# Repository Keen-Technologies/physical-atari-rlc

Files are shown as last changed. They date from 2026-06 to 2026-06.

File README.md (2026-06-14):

# **[Physical Atari: A Robust and Accessible Platform for Real-time Reinforcement Learning on Robots](https://keenagi.com/research/physical-atari/)**  
Khurram Javed, Joseph Modayil, Gloria Kennickell, Richard S. Sutton, John Carmack

## Overview

- **Devbox** (Raspberry Pi): runs `PhysicalALE`, displays the game and AprilTags on a Waveshare screen.
- **Agent machine** (Linux): camera observes the Devbox screen, Robotroller servos press the joystick, and `agent_code` runs training/evaluation.

## Setup

### 1. Build Robotroller

- Follow the [Robotroller assembly guide](https://keenagi.com/research/physical-atari/robotroller.html).
- Configure servo IDs and baud rate before first use (see [Hardware setup](#hardware-setup) below).

### 2. Set up the Devbox

The microSD card cannot be inserted or removed once the chassis is built. Order:

1. Flash **Raspberry Pi OS Full** (64-bit, Debian 13 "trixie") and insert the SD card — see [devbox_code/README.md](devbox_code/README.md#flash-raspberry-pi-os).
2. Assemble the Devbox — follow the [Devbox assembly guide](https://keenagi.com/research/physical-atari/devbox.html).
3. Clone this repository, install dependencies, and build `PhysicalALE` (see [devbox_code/README.md](devbox_code/README.md)).
4. Place Atari 2600 ROMs in a directory (e.g. `devbox_code/games/`).
5. Launch a game: `PhysicalALE ./games/ pong`

### 3. Set up the agent machine

On the Linux machine with the camera and Robotroller:

1. Build and install the I/O library (see [input_output_cpp_library/README.md](input_output_cpp_library/README.md)).
2. Install Python dependencies:
   ```bash
   cd agent_code
   pip install -r requirements.txt
   ```
3. Create a local Robotroller config (see [agent_code/README.md#robotroller-config](agent_code/README.md#robotroller-config)):
   ```bash
   cp physical_atari_configs/robotroller.default.json physical_atari_configs/physical_atari_sample_config.json
   ```
   Edit `physical_atari_sample_config.json` for your camera device and serial port.

### 4. Run a random agent

With the Devbox running a game:

```bash
# On Devbox
PhysicalALE ./games/ pong

# On agent machine (from agent_code/)
python learn_policy.py --config experiment_configs/agent_random_real.json --run 0
```

For sim-only testing (no hardware), see [agent_code/README.md](agent_code/README.md).

## Hardware setup

Before using the physical environment, configure each Dynamixel XC330 servo. Factory defaults are ID **1** and baud rate **57600**. The Robotroller expects three servos on the same bus at baud rate **1,000,000**:

| ID | Role |
|----|---|
| 50 | Fire button |
| 51 | Left/right D-pad |
| 52 | Up/down D-pad |

Configure one servo at a time (only one device on the bus during programming):

1. Connect a USB serial adapter to the **agent machine** (not the Devbox).
2. Install dependencies: from the repository root, `pip install -r setup_scripts/requirements.txt`
3. Find the serial port: `ls /dev/serial/by-id/`
4. Connect **one** servo and power it.
5. Assign the target ID with [`setup_scripts/change_id.py`](setup_scripts/change_id.py) (use `--baud_rate 57600` for factory-default servos).
6. Set baud rate to 1,000,000 with [`setup_scripts/change_baud_rate.py`](setup_scripts/change_baud_rate.py).
7. Disconnect that servo, connect the next, and repeat.

Set `SERIAL` to your device path. Example for the fire-button servo:

```bash
# Assign ID 50 (communicate at factory baud 57600)
python setup_scripts/change_id.py --path "$SERIAL" --current_id 1 --new_id 50 --baud_rate 57600

# Switch servo to 1 Mbps (required by the Robotroller library)
python setup_scripts/change_baud_rate.py --path "$SERIAL" --id 50 --current_baud_rate 57600 --new_baud_rate 1000000
```

Repeat for the left/right servo (ID 51) and up/down servo (ID 52).

Once all three servos are configured, connect them together on the same bus. Set `robot.serial_port` in your Robotroller config — see [agent_code/README.md#robotroller-config](agent_code/README.md#robotroller-config).

## Repository layout

| Directory | Purpose |
|---|---|
| [`agent_code/`](agent_code/) | RL training, evaluation, and finetuning ([README](agent_code/README.md)) |
| [`devbox_code/`](devbox_code/) | Devbox emulator (`PhysicalALE`) ([README](devbox_code/README.md)) |
| [`input_output_cpp_library/`](input_output_cpp_library/) | Camera, AprilTag, and servo I/O (`robotroller` module) ([README](input_output_cpp_library/README.md)) |
| [`setup_scripts/`](setup_scripts/) | Dynamixel servo ID and baud rate configuration |
| [`3d_model_files/`](3d_model_files/) | Printable STLs, Blender/Fusion archives, and exchange formats for Devbox and Robotroller |

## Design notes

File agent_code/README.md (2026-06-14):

# Agent scripts

Run commands from the `agent_code/` directory. For hardware assembly and servo setup, see the [root README](../README.md).

Install dependencies with `pip install -r requirements.txt`. **ale-py 0.12+** is required (older versions return action IDs differently and break `sim_env`).

Training runs save checkpoints to local directories (see `checkpoint_dir` in experiment configs).

For visualization and camera tools, see [scripts/README.md](scripts/README.md).

## Robotroller config

Physical runs need a machine-specific robotroller config (camera and servo settings). Config files live under `agent_code/physical_atari_configs/`:

| File | Purpose |
|---|---|
| `physical_atari_configs/robotroller.default.json` | Committed template with default values |
| `physical_atari_configs/physical_atari_sample_config.json` | Local config used at runtime (gitignored) |

Copy the template to create your local config, then edit camera and robot settings for your machine:

```bash
cp physical_atari_configs/robotroller.default.json physical_atari_configs/physical_atari_sample_config.json
```

Edit `physical_atari_sample_config.json` (e.g. `camera.device`, `robot.serial_port`, servo positions).

Physical experiment configs (e.g. `experiment_configs/agent_action_input_real.json`) specify the config path:

```json
"robotroller_config_path": ["./physical_atari_configs/physical_atari_sample_config.json"]
```

The resolved path is stored in checkpoint `results.json` so `evaluate_policy.py` and `finetune_policy.py` can reuse it when run with `--env real`. Override with `--robotroller-config` if needed.

If you have an existing home-directory config, copy it once:

```bash
cp ~/robotroller.conf physical_atari_configs/physical_atari_sample_config.json
```

## agent_random

Test the sim or physical stack with random actions (replaces the old `test_python.py` hardware test). The agent picks a new uniform random action every frame; no training or weight checkpoints are saved (`store_weights: false` in the random experiment configs).

For physical runs, set up your robotroller config first (see **Robotroller config** above).

Sim test:

```bash
python learn_policy.py --config experiment_configs/agent_random_sim.json --run 0
```

Physical test (launch the game on the devbox first, e.g. `PhysicalALE ./games/ pong`):

```bash
python learn_policy.py --config experiment_configs/agent_random_real.json --run 0
```

## learn_policy.py

Trains or benchmarks an agent based on a configuration file.

### Usage

```bash
python learn_policy.py --config experiment_configs/agent_action_input_sim.json --run 0
```

Checkpoints are written to `{checkpoint_dir}/{run_name}/` with `results.json`, `weights.pkl`, and observation state files.

### Arguments

*   `--config`: Path to the JSON configuration file containing hyperparameters.
*   `--run`: Integer index to select a specific configuration from the cross-product of parameters defined in the JSON file.
*   `--gpu`: (Optional) GPU device ID to use.

### Physical environment

Launch the game on the devbox before training:

```bash
# On devbox
PhysicalALE ./games/ pong

# On agent machine
python learn_policy.py --config experiment_configs/agent_action_input_real.json --run 0
```

The default real config (`experiment_configs/agent_action_input_real.json`) sets `device` to `cuda`. Change it to `cpu` in that JSON if you do not have a CUDA GPU.

---

## evaluate_policy.py

Loads a trained model from a checkpoint directory and evaluates its performance.

### Usage

```bash
python evaluate_policy.py --checkpoint-dir ./checkpoints/pong__agents.agent_action_input__0__20260612-120000
```

### Arguments

*   `--checkpoint-dir`: Path to a training run directory (contains `results.json` and `weights.pkl`).
*   `--eval_steps`: Number of steps to run the evaluation (default: 20000).
*   `--device`: Device to run evaluation on (e.g., `cpu`, `cuda`, `mps`).
*   `--env`: Environment type (`sim` or `real`; default: `sim`).
*   `--robotroller-config`: Path to robotroller config when `--env real` (overrides checkpoint).
*   `--comment`: Optional comment logged with evaluation results.

Eval results are saved to `{checkpoint-dir}/eval_results.json`.

---

## finetune_policy.py

Loads a trained model, evaluates it (pre-finetune), fine-tunes it, and evaluates again (post-finetune).

### Usage

```bash
python finetune_policy.py --checkpoint-dir ./checkpoints/pong__...__0__<timestamp> --learning_steps 100000
```

### Arguments

*   `--checkpoint-dir`: Path to source checkpoint run directory.
*   `--eval_before_steps`: Evaluation steps before fine-tuning (default: 18000).
*   `--learning_steps`: Number of fine-tuning steps (required).
*   `--eval_after_steps`: Evaluation steps after fine-tuning (default: 18000).
*   `--device`: Device to run on (e.g., `cpu`, `cuda`, `mps`).
*   `--env`: Environment type (`sim` or `real`; default: `sim`).
*   `--robotroller-config`: Path to robotroller config when `--env real` (overrides checkpoint).
*   `--comment`: Optional comment logged with finetune results.

Fine-tuned weights are saved to a new run directory under `checkpoint_dir`. Summary metrics are written to `{checkpoint-dir}/finetune_results.json`.

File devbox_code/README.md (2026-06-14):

# Devbox Setup

Order of operations:

1. Flash the OS and insert the SD card (the microSD slot is not accessible after assembly).
2. Assemble the Devbox chassis.
3. Clone this repository and build `PhysicalALE`.

Runs on a Raspberry Pi devbox: builds and runs the Stella-based Atari emulator (`PhysicalALE`) with AprilTag overlays and GPIO input.

## Flash Raspberry Pi OS

Use a fresh install of **Raspberry Pi OS Full** (Debian 13 "trixie", 64-bit). Do not upgrade from Bookworm in place — flash a clean image.

1. Download and install [Raspberry Pi Imager](https://www.raspberrypi.com/software/) on your computer.
2. Insert the Devbox microSD card (or connect the Pi's storage via USB).
3. In Imager:
   - **Choose Device** → **Raspberry Pi 5**
   - **Choose OS** → **Raspberry Pi OS (other)** → **Raspberry Pi OS Full (64-bit)**
   - **Choose Storage** → your microSD card
4. Open **OS Customisation** (gear icon) and set hostname, user, password, locale, and Wi‑Fi if needed. Enable SSH if you plan to set up headlessly.
5. Click **Write**, then insert the card into the Pi.

Insert the SD card **before** assembling the chassis — the slot is not accessible afterward.

## Assemble the Devbox

Follow the [Devbox assembly guide](https://keenagi.com/research/physical-atari/devbox.html).

## Install software

On the assembled Devbox, clone this repository and work from the `devbox_code` directory.

Update the system:

```sh
sudo apt update && sudo apt full-upgrade -y
```

Install build dependencies:

```sh
sudo apt install -y libsdl2-dev libgpiod-dev cmake build-essential pkg-config
```

Build and install `PhysicalALE`:

```sh
cd devbox_code
mkdir -p build && cd build
cmake ..
make -j"$(nproc)"
sudo make install   # installs PhysicalALE to /usr/local/bin
```

## ROM files

We do not ship ROM files in this repository. You must place supported Atari 2600 ROMs in a directory (e.g. `./games/`) before running `PhysicalALE`.

The easiest way to get them is via [ale_py](https://github.com/Farama-Foundation/Arcade-Learning-Environment), which bundles supported ROMs in the pip package (ale-py 0.12+):

```sh
pip install ale-py
mkdir -p games
python3 -c "from ale_py import roms; import shutil; from pathlib import Path; d=Path('games'); [shutil.copy(p, d/f'{n}.bin') for n in roms.get_all_rom_ids() if (p:=roms.get_rom_path(n))]"
```

On Raspberry Pi OS, if `pip install` fails because system Python is externally managed, use a virtual environment or pass `--break-system-packages` to `pip install ale-py`.

## Run

```sh
cd devbox_code
PhysicalALE ./games/ pong
PhysicalALE ./games/ pong my_experiment   # optional override for results filename
```

Usage: `PhysicalALE <RomDirectory> <game_name> [results_filename]`

On shutdown, results are saved locally to `{game_name}_{timestamp}.json` (UTC). Pass an optional third argument to override the filename (saved as `{results_filename}.json`).

## Keyboard controls

Requires a USB keyboard connected to the Pi.

- `T`: Toggle corner AprilTag visibility
- `F`: Toggle FPS counter
- `Q`: Quit

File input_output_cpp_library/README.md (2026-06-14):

# input_output_cpp_library

I/O layer for the physical Atari setup: camera capture, AprilTag detection, and Robotroller servo actions. The primary deliverable is the `robotroller` Python module, which exposes `PhysicalAtariEnv` (used by RL training), `Camera`, and `Robotroller`.

**Prerequisites:** Build the Robotroller hardware, assign servo IDs 50, 51, and 52, and set baud rate to 1,000,000 — see [Hardware setup](../README.md#hardware-setup) in the root README.

For hardware config, tests, and training scripts, see [agent_code/README.md](../agent_code/README.md).

## 1. Install dependencies

### Ubuntu

```bash
sudo apt update
sudo apt install -y build-essential cmake git libopencv-dev python3-dev python3-pybind11 libapriltag-dev
```

### Dynamixel SDK

```bash
git clone https://github.com/ROBOTIS-GIT/DynamixelSDK.git
cd DynamixelSDK/c++
mkdir build && cd build
cmake ..
make
sudo make install
cd ../../..
```

### Miniconda (optional)

For Python environment management:

```bash
wget https://repo.anaconda.com/miniconda/Miniconda3-latest-Linux-x86_64.sh
bash Miniconda3-latest-Linux-x86_64.sh
source ~/.bashrc
```

## 2. Build and install

Build from the same Python environment you will use for training — `cmake` installs the module into the active `python` interpreter's site-packages.

```bash
cd input_output_cpp_library
mkdir -p build && cd build
cmake ..
make
sudo make install
```

Verify the module is available:

```bash
python3 -c "import robotroller; print(robotroller.__doc__)"
```

## License

Copyright 2026 Keen Technologies, Inc.

Licensed under the Apache License, Version 2.0. See the [repository LICENSE](../LICENSE) for the full text.

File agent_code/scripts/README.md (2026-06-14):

# Scripts

Run these from the `agent_code/` directory.

## visualize_stream.py

Records agent observations from the sim or real environment to an MP4.

```bash
# Sim
python scripts/visualize_stream.py \
  --env sim \
  --game pong \
  --output pong_sim.mp4

# Real (game must be running on the devbox; create physical_atari_sample_config.json first — see agent README Robotroller config)
python scripts/visualize_stream.py \
  --env real \
  --config physical_atari_configs/physical_atari_sample_config.json \
  --game pong \
  --output pong_real.mp4
```

Common flags: `--frames` (default 1000), `--output-fps` (default 30), `--random-policy`, `--no-text`.

## camera_focus_sweep.py

Records a video while sweeping camera focus from 200 to 600 (step 10, 2s per value). Writes `focus_sweep.mp4`.

```bash
python scripts/camera_focus_sweep.py \
  --config-path physical_atari_configs/robotroller.default.json
```

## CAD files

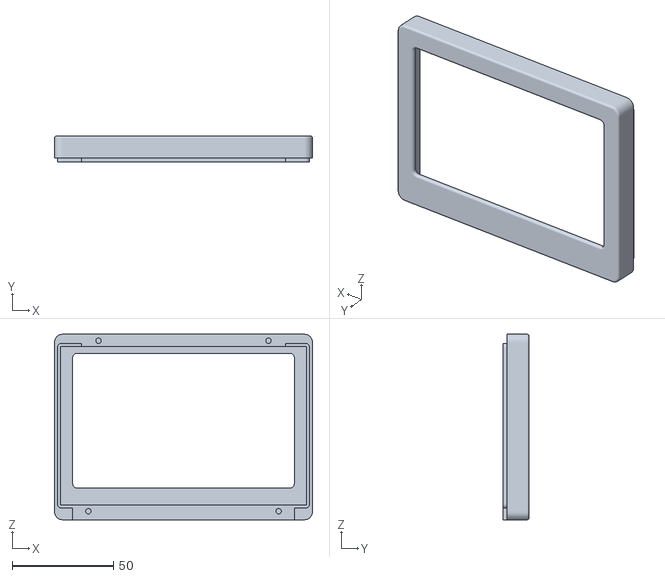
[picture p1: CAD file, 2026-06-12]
3d_model_files/3d_printer_files/devbox/Front.stl
127.5 x 13.0 x 91.7

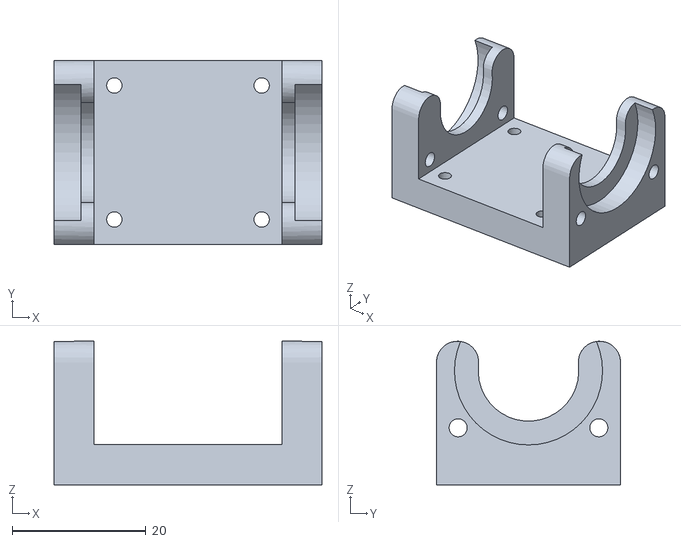
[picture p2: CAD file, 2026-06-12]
3d_model_files/3d_printer_files/robotroller/shoulder.stl
40.0 x 27.5 x 21.4

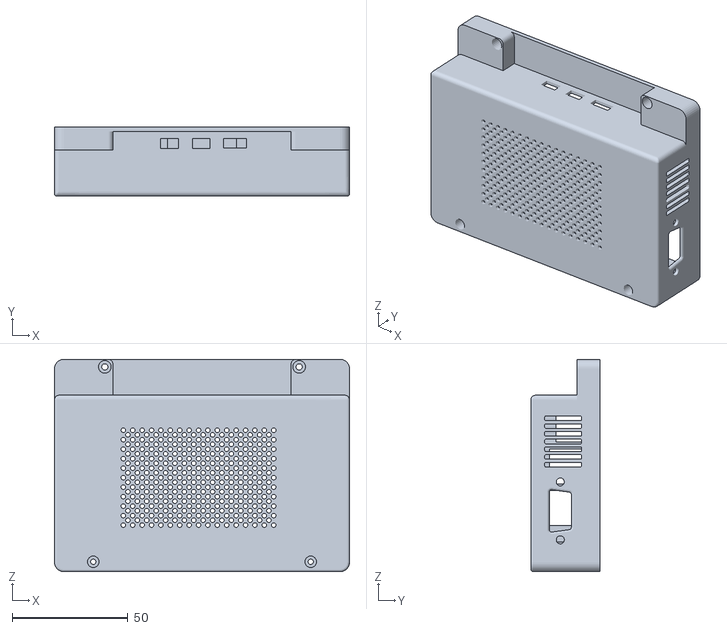
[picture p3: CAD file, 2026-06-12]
3d_model_files/3d_printer_files/devbox/Back.stl
127.5 x 30.0 x 91.7

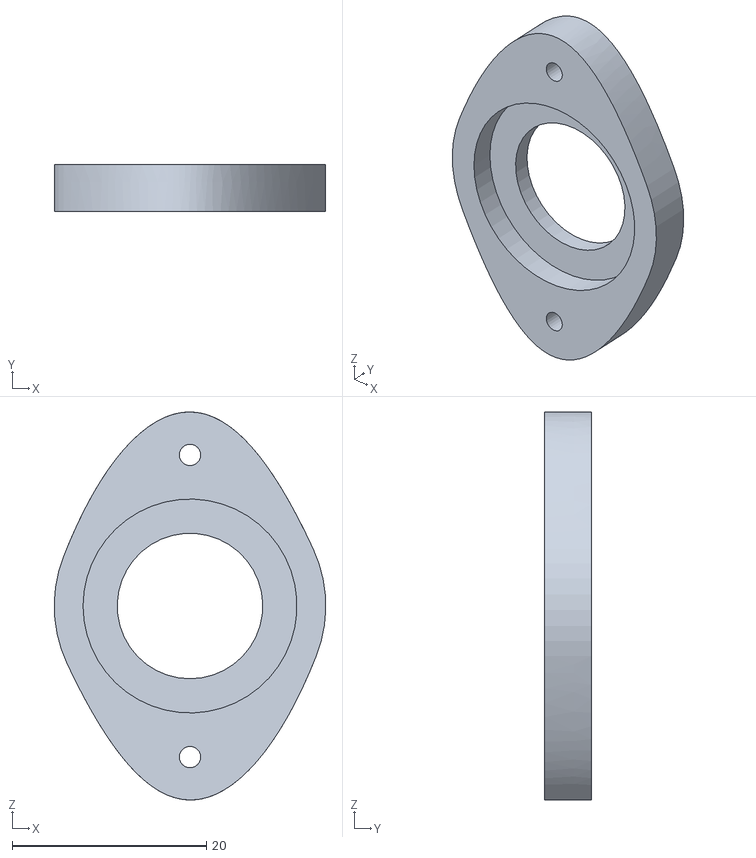
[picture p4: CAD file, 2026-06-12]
3d_model_files/3d_printer_files/robotroller/elbow_cover.stl
28.0 x 4.80 x 40.0

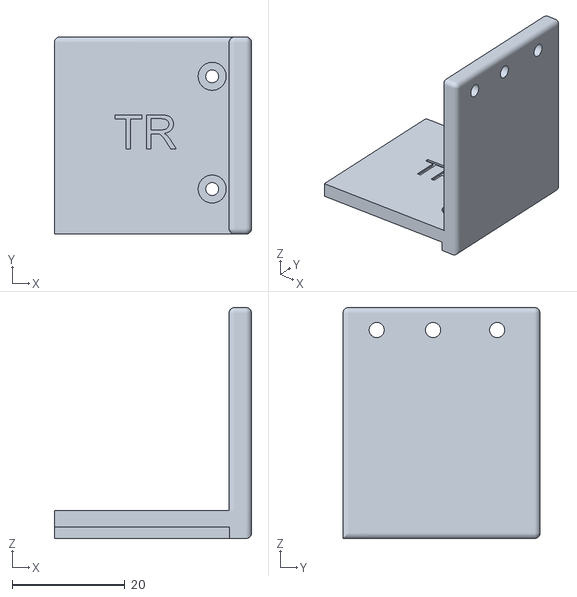
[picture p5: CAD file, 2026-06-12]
3d_model_files/3d_printer_files/robotroller/tr_corner.stl
35.0 x 35.0 x 41.0

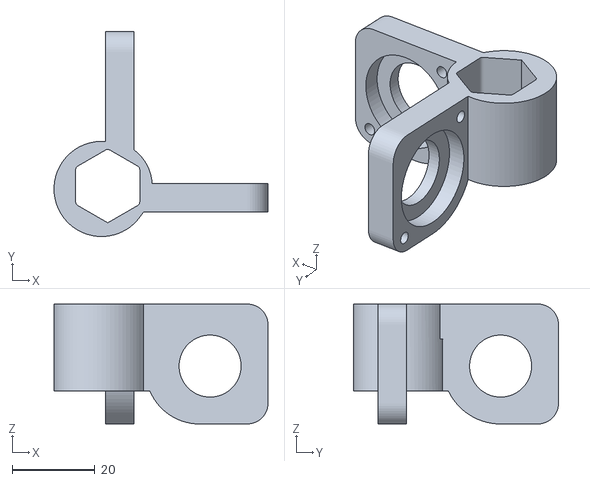
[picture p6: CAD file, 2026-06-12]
3d_model_files/3d_printer_files/robotroller/joystick_attachment.stl
51.7 x 49.6 x 29.0

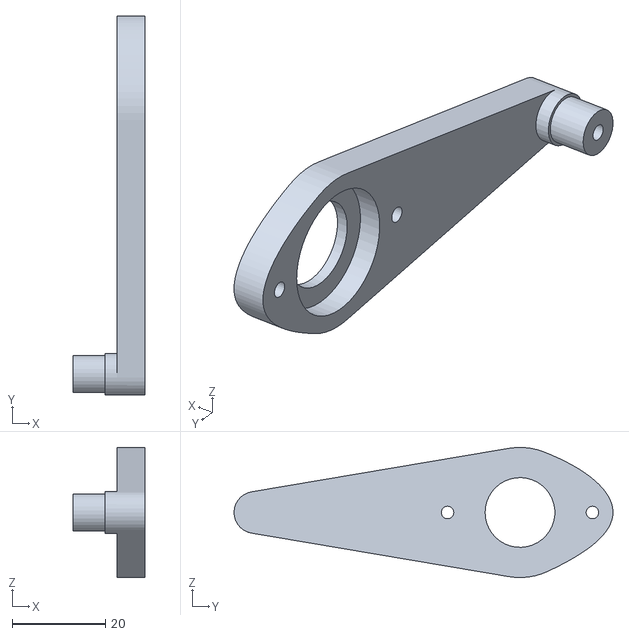
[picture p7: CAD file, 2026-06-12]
3d_model_files/3d_printer_files/robotroller/elbow_to_finger.stl
15.4 x 81.5 x 28.0

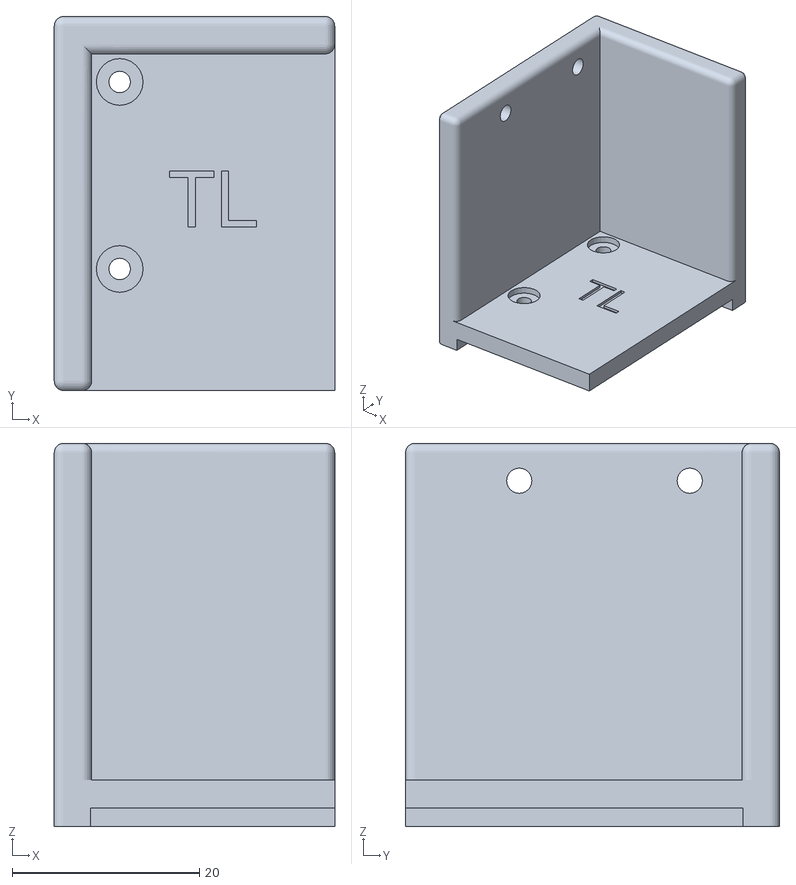
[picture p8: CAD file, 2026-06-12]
3d_model_files/3d_printer_files/robotroller/tl_corner.stl
30.0 x 40.0 x 41.0

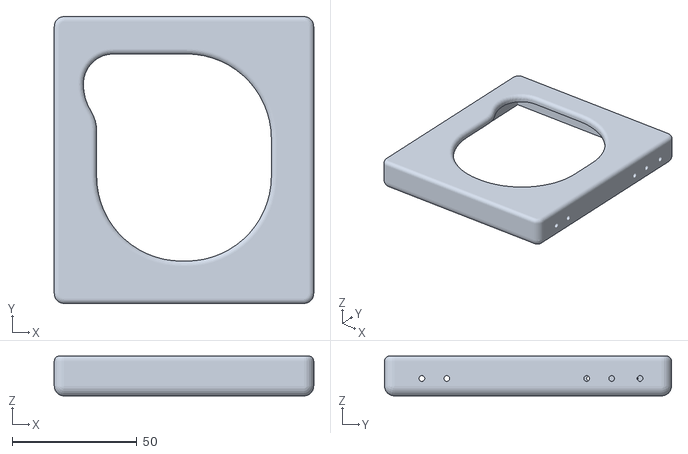
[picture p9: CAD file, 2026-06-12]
3d_model_files/3d_printer_files/robotroller/cx40_cover.stl
104.0 x 115.0 x 16.0

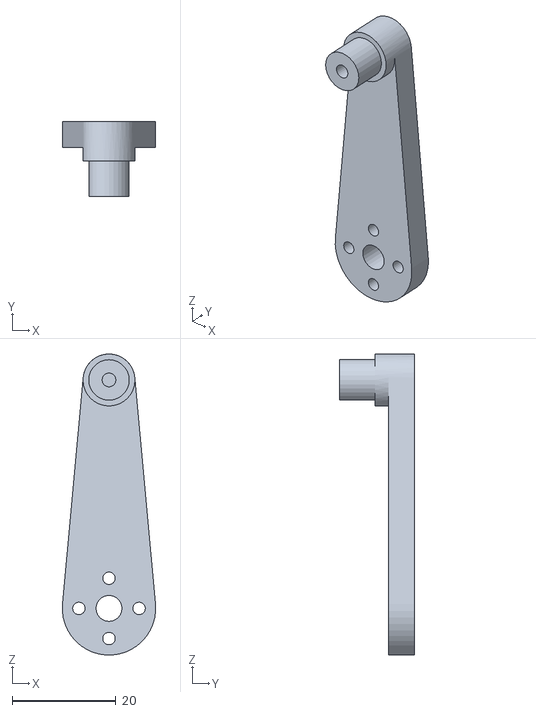
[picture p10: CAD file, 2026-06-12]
3d_model_files/3d_printer_files/robotroller/motor_attachment.stl
18.0 x 14.4 x 58.0

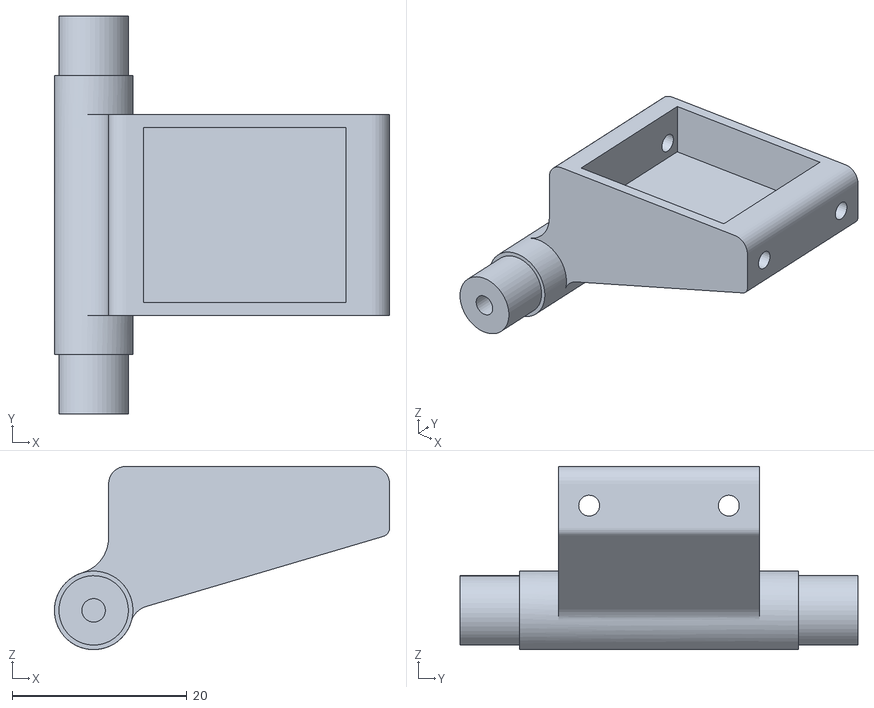
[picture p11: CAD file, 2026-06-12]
3d_model_files/3d_printer_files/robotroller/shoulder_joint.stl
38.4 x 45.6 x 21.0

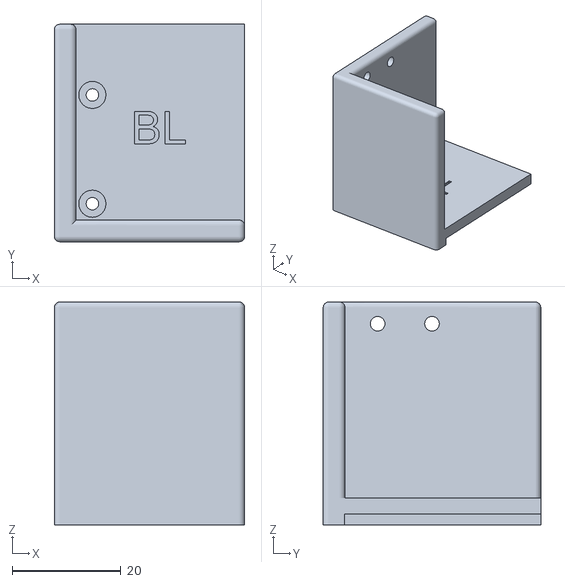
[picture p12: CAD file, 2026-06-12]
3d_model_files/3d_printer_files/robotroller/bl_corner.stl
35.0 x 40.0 x 41.0

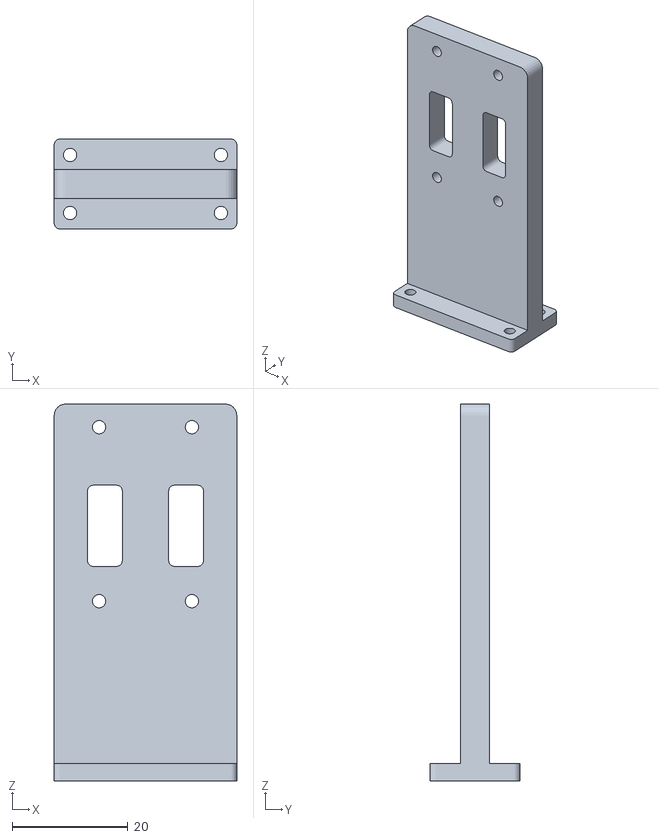
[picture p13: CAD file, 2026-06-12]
3d_model_files/3d_printer_files/robotroller/fire_finger_holder.stl
31.5 x 15.5 x 65.0

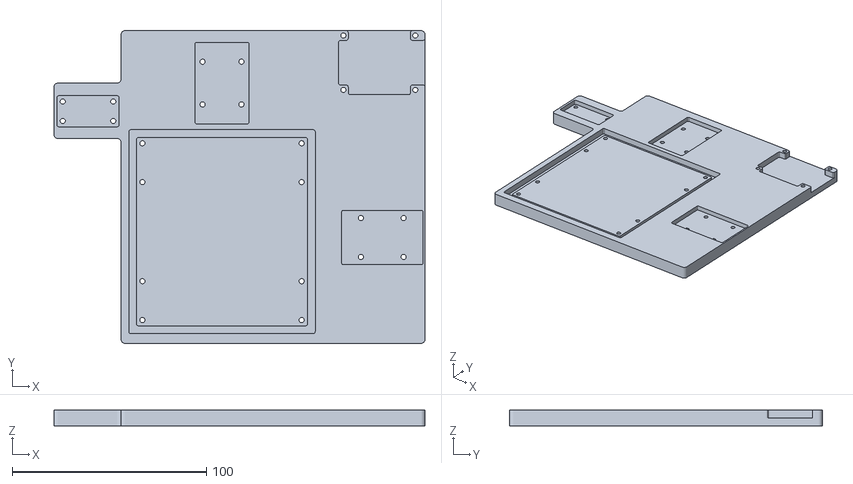
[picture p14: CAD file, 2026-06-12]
3d_model_files/3d_printer_files/robotroller/base_plate.stl
191.0 x 161.0 x 8.00

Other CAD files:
3d_model_files/3d_printer_files/robotroller/shoulder_socket_cover.stl
3d_model_files/3d_printer_files/robotroller/br_corner.stl
3d_model_files/3d_printer_files/robotroller/joystick_attachment_cover.stl
3d_model_files/3d_printer_files/robotroller/fire_finger.stl
3d_model_files/3d_printer_files/robotroller/washer.stl

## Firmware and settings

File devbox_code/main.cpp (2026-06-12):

// Copyright 2026 Keen Technologies, Inc.
//
// Licensed under the Apache License, Version 2.0 (the "License");
// you may not use this file except in compliance with the License.
// You may obtain a copy of the License at
//
//     http://www.apache.org/licenses/LICENSE-2.0
//
// Unless required by applicable law or agreed to in writing, software
// distributed under the License is distributed on an "AS IS" BASIS,
// WITHOUT WARRANTIES OR CONDITIONS OF ANY KIND, either express or implied.
// See the License for the specific language governing permissions and
// limitations under the License.

#include "imgui/imgui.h"
#include "imgui/imgui_impl_sdl2.h"
#include "imgui/imgui_impl_sdlrenderer2.h"
#include "imgui/imgui_theme.h"
#include <chrono>
#include <fstream>

#include <iostream>
#include <vector>
#include <csignal>
#include <cerrno>
#include <cstring>
#include <unordered_map>

#include <gpiod.h>
#include <SDL2/SDL.h>
#include <mutex>
#include "src/atari/ale_interface.hpp"
#include "include/json.hpp"


// Screen Settings
int screen_width = 1280;
int screen_height = 720;

// SDL Core Components
SDL_Window* window;
SDL_Renderer* renderer;
SDL_Texture* game_screen;

// Frame Timing
double fps_estimate = 60;

// ALE Environment and Configuration
ale::ALEInterface* env;
ale::Action current_action = ale::PLAYER_A_NOOP;

// Game State and Rendering
std::vector<unsigned char> input_image;

// Synchronization
std::mutex m;

// Episodic tracking
std::vector<int> episodic_scores;
std::vector<int> episode_lengths;
int current_episode_score = 0;
std::string experiment_name;
std::string game_name_global;
std::chrono::system_clock::time_point start_timestamp;
bool shutdown_requested = false;

static gpiod_line_request* request_input_lines(const char* chip_path,
                                               const unsigned int* offsets,
                                               size_t num_lines,
                                               const char* consumer)
{
    gpiod_chip* chip = gpiod_chip_open(chip_path);
    if (!chip)
        return nullptr;

    gpiod_line_settings* settings = gpiod_line_settings_new();
    if (!settings)
    {
        gpiod_chip_close(chip);
        return nullptr;
    }

    gpiod_line_settings_set_direction(settings, GPIOD_LINE_DIRECTION_INPUT);
    gpiod_line_settings_set_bias(settings, GPIOD_LINE_BIAS_PULL_UP);

    gpiod_line_config* line_cfg = gpiod_line_config_new();
    if (!line_cfg)
    {
        gpiod_line_settings_free(settings);
        gpiod_chip_close(chip);
        return nullptr;
    }

    for (size_t i = 0; i < num_lines; ++i)
    {
        if (gpiod_line_config_add_line_settings(line_cfg, &offsets[i], 1, settings) < 0)
        {
            gpiod_line_config_free(line_cfg);
            gpiod_line_settings_free(settings);
            gpiod_chip_close(chip);
            return nullptr;
        }
    }

    gpiod_request_config* req_cfg = nullptr;
    if (consumer)
    {
        req_cfg = gpiod_request_config_new();
        if (!req_cfg)
        {
            gpiod_line_config_free(line_cfg);
            gpiod_line_settings_free(settings);
            gpiod_chip_close(chip);
            return nullptr;
        }
        gpiod_request_config_set_consumer(req_cfg, consumer);
    }

    gpiod_line_request* request = gpiod_chip_request_lines(chip, req_cfg, line_cfg);

    gpiod_request_config_free(req_cfg);
    gpiod_line_config_free(line_cfg);
    gpiod_line_settings_free(settings);
    gpiod_chip_close(chip);

    return request;
}

static int gpio_pressed(gpiod_line_request* request, unsigned int offset)
{
    enum gpiod_line_value value = gpiod_line_request_get_value(request, offset);
    return value == GPIOD_LINE_VALUE_ACTIVE ? 0 : 1;
}

// Signal handler for graceful shutdown
void signal_handler(int signum)
{
    std::cout << "\n[PhysicalALE] Received signal " << signum << ", shutting down gracefully..." << std::endl;
    m.lock();
    shutdown_requested = true;
    m.unlock();
}

// Function to get ISO 8601 timestamp string
std::string get_iso_timestamp(const std::chrono::system_clock::time_point& tp)
{
    auto time_t_tp = std::chrono::system_clock::to_time_t(tp);
    std::tm tm = *std::gmtime(&time_t_tp);
    char buffer[100];
    std::strftime(buffer, sizeof(buffer), "%Y-%m-%dT%H:%M:%SZ", &tm);
    return std::string(buffer);
}

std::string get_filename_timestamp(const std::chrono::system_clock::time_point& tp)
{
    auto time_t_tp = std::chrono::system_clock::to_time_t(tp);
    std::tm tm = *std::gmtime(&time_t_tp);
    char buffer[32];
    std::strftime(buffer, sizeof(buffer), "%Y%m%d_%H%M%S", &tm);
    return std::string(buffer);
}

// Function to save results to JSON file
void save_results_to_json()
{
    try
    {
        std::cout << "[PhysicalALE] Saving results to JSON file..." << std::endl;
        
        // Create end timestamp
        auto end_timestamp = std::chrono::system_clock::now();
        
        // Build JSON document
        nlohmann::json j;
        j["experiment_name"] = experiment_name;
        j["game"] = game_name_global;
        j["episodic_scores"] = episodic_scores;
        j["episode_lengths"] = episode_lengths;
        j["start_timestamp"] = get_iso_timestamp(start_timestamp);
        j["end_timestamp"] = get_iso_timestamp(end_timestamp);
        
        std::string filename = experiment_name.empty()
            ? game_name_global + "_" + get_filename_timestamp(end_timestamp) + ".json"
            : experiment_name + ".json";
        std::ofstream output_file(filename);
        if (!output_file.is_open())
        {
            std::cerr << "[PhysicalALE] Error: Could not open output file " << filename << std::endl;
            return;
        }
        
        output_file << j.dump(4);  // Pretty print with 4-space indent
        output_file.close();
        
        std::cout << "[PhysicalALE] Results saved to " << filename << std::endl;
        std::cout << "[PhysicalALE] Total episodes: " << episodic_scores.size() << std::endl;
    }
    catch (const std::exception& e)
    {
        std::cerr << "[PhysicalALE] Error saving results to JSON: " << e.what() << std::endl;
    }
}

// Function to generate AprilTag
void GenerateAprilTag(unsigned char* aprilTag, const std::vector<int>& indices)
{
    for (int i = 0; i < 10 * 10 * 4; i++)
    {
        aprilTag[i] = 0;
    }
    for (int i = 0; i < 10; i++)
    {
        for (int j = 0; j < 10; j++)
        {
            if (i == 0 || j == 0 || i == 9 || j == 9)
            {
                aprilTag[i * 10 * 4 + j * 4 + 0] = 255;
                aprilTag[i * 10 * 4 + j * 4 + 1] = 255;
                aprilTag[i * 10 * 4 + j * 4 + 2] = 255;
                aprilTag[i * 10 * 4 + j * 4 + 3] = 255;
            }
        }
    }
    for (auto& ind : indices)
    {
        aprilTag[(ind - 1) * 4 + 0] = 255;
        aprilTag[(ind - 1) * 4 + 1] = 255;
        aprilTag[(ind - 1) * 4 + 2] = 255;
        aprilTag[(ind - 1) * 4 + 3] = 255;
    }
}


int main(int argc, char** argv)
{
    // Record start timestamp
    start_timestamp = std::chrono::system_clock::now();
    
    float frac = 0.625f;

    // Get RomDirectory from command line arguments
    if (argc < 2)
    {
        std::cerr << "Error: RomDirectory required as first command line argument" << std::endl;
        std::cerr << "Usage: " << argv[0] << " <RomDirectory> <game_name> [results_filename]" << std::endl;
        return 1;
    }
    std::string directory = argv[1];

    std::unordered_map<std::string, bool> to_render_flags_map;
    to_render_flags_map["corner_tags"] = true;

    // Get game name and experiment name from command line arguments
    if (argc < 3)
    {
        std::cerr << "Error: Game name required as command line argument" << std::endl;
        std::cerr << "Usage: " << argv[0] << " <RomDirectory> <game_name> [results_filename]" << std::endl;
        return 1;
    }
    std::string game_name = argv[2];
    game_name_global = game_name;
    
    // Get experiment name (optional)
    if (argc >= 4)
    {
        experiment_name = argv[3];
    }
    else
    {
        experiment_name = "";
    }
    
    std::cout << "Game: " << game_name << ", Experiment: " << experiment_name << std::endl;

    // Register signal handler for graceful shutdown
    signal(SIGTERM, signal_handler);
    signal(SIGINT, signal_handler);

    env = new ale::ALEInterface();
    env->setFloat("repeat_action_probability", 0.0);
    env->setInt("frame_skip", 1);
    env->setBool("truncate_on_loss_of_life", false);
    // Ensure directory has trailing slash for proper path joining
    std::string rom_path = directory;
    if (!rom_path.empty() && rom_path.back() != '/') {
        rom_path += "/";
    }
    rom_path += game_name + ".bin";
    env->loadROM(rom_path);

    env->reset_game();
    std::cout << "Env reset complete\n";
    env->act(ale::PLAYER_A_NOOP);
    SDL_Init(SDL_INIT_VIDEO);
    SDL_DisplayMode DM;
    SDL_GetCurrentDisplayMode(0, &DM);

    auto window_flags = static_cast<SDL_WindowFlags>(
        SDL_WINDOW_FULLSCREEN);
    window = SDL_CreateWindow("Atari 2600", SDL_WINDOWPOS_CENTERED,
                              SDL_WINDOWPOS_CENTERED, screen_width, screen_height, window_flags);

    renderer = SDL_CreateRenderer(
        window, -1, SDL_RENDERER_PRESENTVSYNC | SDL_RENDERER_ACCELERATED);
    if (renderer == nullptr)
    {
        SDL_Log("Error creating SDL_Renderer!");
        return 0;
    }

    IMGUI_CHECKVERSION();
    ImGui::CreateContext();
    ImGuiIO& io = ImGui::GetIO();
    (void)io;
    io.ConfigFlags |=
        ImGuiConfigFlags_NavEnableKeyboard; // Enable Keyboard Controls
    io.ConfigFlags |=
        ImGuiConfigFlags_NavEnableGamepad; // Enable Gamepad Controls

    ImGui_ImplSDL2_InitForSDLRenderer(window, renderer);
    ImGui_ImplSDLRenderer2_Init(renderer);

    ImGuiTheme::ApplyTheme(ImGuiTheme::ImGuiTheme_GrayVariations);

    bool done = false;
    int pitch2 = 0;
    void* pixels2;

    std::vector<std::vector<int>> indices = {};
    std::vector<int> tag0 = {23, 24, 26, 28, 34, 35, 36, 38, 44, 45, 53, 55, 64, 66, 67, 76};
    std::vector<int> tag1 = {23, 24, 26, 27, 34, 36, 37, 38, 43, 44, 45, 46, 54, 55, 63, 65, 66, 68, 75, 78};
    std::vector<int> tag2 = {23, 24, 26, 27, 28, 34, 37, 43, 55, 58, 66, 75, 76, 77};
    std::vector<int> tag3 = {23, 24, 25, 28, 36, 37, 38, 43, 46, 47, 48, 53, 55, 58, 63, 64, 67, 74, 75};
    std::vector<int> tag4 = {23, 24, 25, 27, 33, 34, 35, 36, 43, 45, 46, 47, 48, 55, 57, 63, 73, 77};
    std::vector<int> tag5 = {23, 24, 25, 26, 33, 34, 38, 43, 44, 46, 47, 53, 55, 57, 58, 65, 66, 67, 73, 75, 76};
    std::vector<int> tag6 = {28, 34, 36, 37, 43, 45, 48, 54, 55, 56, 58, 67, 76, 78};
    std::vector<int> tag7 = {26, 36, 37, 44, 46, 53, 55, 56, 57, 66, 67, 68, 74, 76};
    std::vector<int> tag8 = {25, 33, 35, 37, 38, 46, 47, 48, 54, 55, 56, 57, 58, 63, 64, 65, 67, 73, 75, 76, 78};
    std::vector<int> tag9 = {25, 28, 33, 36, 38, 43, 45, 47, 48, 54, 64, 68, 73, 74, 77};
    std::vector<int> tag10 = {25, 26, 28, 35, 36, 37, 38, 43, 44, 45, 47, 54, 58, 63, 65, 66, 67, 76, 77};
    std::vector<int> tag11 = {25, 26, 27, 28, 33, 34, 35, 36, 37, 38, 43, 46, 48, 53, 57, 63, 64, 67, 68, 74, 76, 78};
    std::vector<int> tag12 = {24, 33, 34, 35, 37, 45, 48, 54, 57, 58, 65, 67, 74, 75, 77};
    std::vector<int> tag13 = {24, 28, 33, 34, 36, 43, 45, 46, 48, 57, 58, 63, 68, 74, 75, 76, 77, 78};
    std::vector<int> tag14 = {24, 27, 28, 33, 35, 38, 43, 44, 46, 53, 56, 65, 66, 67, 68, 73, 75, 78};
    std::vector<int> tag15 = {24, 26, 33, 36, 44, 45, 54, 56, 63, 66, 67, 73, 75, 76, 77};
    std::vector<int> tag16 = {24, 26, 27, 34, 35, 38, 44, 45, 46, 47, 48, 53, 54, 56, 58, 64, 66, 73, 74, 75};
    std::vector<int> tag17 = {24, 25, 27, 36, 37, 43, 45, 46, 47, 53, 54, 56, 57, 63, 64, 68, 75, 76};
    std::vector<int> tag18 = {24, 25, 27, 33, 34, 35, 36, 37, 44, 47, 53, 56, 57, 58, 65, 73, 74, 78};
    std::vector<int> tag19 = {24,25, 26, 27, 28, 33, 37, 38, 46, 48, 54, 55, 63, 64, 65, 67, 68, 73, 75, 77};
    indices = {
        tag0, tag1, tag2, tag3, tag4, tag5, tag6, tag7, tag8, tag9, tag10, tag11, tag12, tag13, tag14, tag15, tag16,
        tag17, tag18, tag19
    };


    std::vector<SDL_Texture*> aprilTagTextures;
    game_screen = SDL_CreateTexture(renderer, SDL_PIXELFORMAT_RGB24, SDL_TEXTUREACCESS_STREAMING,
                                    static_cast<int>(env->getWidth()),
                                    static_cast<int>(env->getHeight()));
    for (int i = 0; i < 36; i++)
    {
        aprilTagTextures.push_back(SDL_CreateTexture(renderer, SDL_PIXELFORMAT_BGR888, SDL_TEXTUREACCESS_STREAMING,
                                                     10,
                                                     10));
    }

    std::vector<unsigned char> aprilTag(10 * 10 * 4, 0);
    for (int i = 0; i < indices.size(); i++)
    {
        GenerateAprilTag(aprilTag.data(), indices[i]);
        if (SDL_LockTexture(aprilTagTextures[i], nullptr, &pixels2, &pitch2) < 0)
        {
            std::cerr << "Failed to lock texture: " << SDL_GetError() << std::endl;
        };
        std::memcpy(pixels2, aprilTag.data(), pitch2 * 10);
        SDL_UnlockTexture(aprilTagTextures[i]);
    }


    auto old_time = std::chrono::system_clock::now();

    int step_counter = 0;
    int last_nonzero_reward_tag = 10;  // Starts at tag 10 (init condition)
    int change_indicator_tag = 15;     // Cycles through 15, 16, 17
    int current_reward = 0;            // Store reward from each step
    bool show_fps = false;


    std::cout << gpiod_api_version() << std::endl;
    static const unsigned int gpio_offsets[] = {17, 27, 22, 24, 23};
    gpiod_line_request* gpio_request = request_input_lines(
        "/dev/gpiochip0", gpio_offsets, sizeof(gpio_offsets) / sizeof(gpio_offsets[0]),
        "PhysicalAtariEnvironment");
    if (!gpio_request)
    {
        std::cerr << "Failed to request GPIO lines: " << strerror(errno) << std::endl;
        return 1;
    }

    while (!done)
    {
        // Check for shutdown request
        m.lock();
        if (shutdown_requested)
        {
            done = true;
            m.unlock();
            break;
        }
        m.unlock();
        
        int up = gpio_pressed(gpio_request, 17);
        int down = gpio_pressed(gpio_request, 27);
        int left = gpio_pressed(gpio_request, 22);
        int right = gpio_pressed(gpio_request, 24);
        int fire = gpio_pressed(gpio_request, 23);

        if (up == 0 && right == 0 && left == 0 && fire == 0 && down == 0) current_action = ale::PLAYER_A_NOOP;
        else if (up == 1 && right == 0 && left == 0 && fire == 0 && down == 0) current_action = ale::PLAYER_A_UP;
        else if (up == 0 && right == 1 && left == 0 && fire == 0 && down == 0) current_action = ale::PLAYER_A_RIGHT;
        else if (up == 0 && right == 0 && left == 1 && fire == 0 && down == 0) current_action = ale::PLAYER_A_LEFT;
        else if (up == 0 && right == 0 && left == 0 && fire == 1 && down == 0) current_action = ale::PLAYER_A_FIRE;
        else if (up == 0 && right == 0 && left == 0 && fire == 0 && down == 1) current_action = ale::PLAYER_A_DOWN;
        else if (up == 1 && right == 1 && left == 0 && fire == 0 && down == 0) current_action = ale::PLAYER_A_UPRIGHT;
        else if (up == 1 && right == 0 && left == 1 && fire == 0 && down == 0) current_action = ale::PLAYER_A_UPLEFT;
        else if (up == 0 && right == 1 && left == 0 && fire == 0 && down == 1) current_action = ale::PLAYER_A_DOWNRIGHT;
        else if (up == 0 && right == 0 && left == 1 && fire == 0 && down == 1) current_action = ale::PLAYER_A_DOWNLEFT;
        else if (up == 1 && right == 0 && left == 0 && fire == 1 && down == 0) current_action = ale::PLAYER_A_UPFIRE;
        else if (up == 0 && right == 1 && left == 0 && fire == 1 && down == 0) current_action = ale::PLAYER_A_RIGHTFIRE;
        else if (up == 0 && right == 0 && left == 1 && fire == 1 && down == 0) current_action = ale::PLAYER_A_LEFTFIRE;
        else if (up == 0 && right == 0 && left == 0 && fire == 1 && down == 1) current_action = ale::PLAYER_A_DOWNFIRE;
        else if (up == 1 && right == 1 && left == 0 && fire == 1 && down == 0)
            current_action =
                ale::PLAYER_A_UPRIGHTFIRE;
        else if (up == 1 && right == 0 && left == 1 && fire == 1 && down == 0)
            current_action =
                ale::PLAYER_A_UPLEFTFIRE;
        else if (up == 0 && right == 0 && left == 1 && fire == 1 && down == 1)
            current_action =
                ale::PLAYER_A_DOWNLEFTFIRE;
        else if (up == 0 && right == 1 && left == 0 && fire == 1 && down == 1)
            current_action =
                ale::PLAYER_A_DOWNRIGHTFIRE;

        ImGui_ImplSDLRenderer2_NewFrame();
        ImGui_ImplSDL2_NewFrame();
        ImGui::NewFrame();
        SDL_Event event;

        while (SDL_PollEvent(&event))
        {
            ImGui_ImplSDL2_ProcessEvent(&event);
            if (event.type == SDL_QUIT)
                done = true;
            if (event.type == SDL_WINDOWEVENT &&
                event.window.event == SDL_WINDOWEVENT_CLOSE &&
                event.window.windowID == SDL_GetWindowID(window))
                done = true;
        }
        step_counter++;
        current_reward = env->act(current_action);
        
        // Accumulate reward for current episode
        current_episode_score += current_reward;
        
        // Update reward tags based on current reward
        if (current_reward > 0)
        {
            last_nonzero_reward_tag = 11;
            change_indicator_tag = (change_indicator_tag == 15) ? 16 : (change_indicator_tag == 16) ? 17 : 15;
        }
        else if (current_reward < 0)
        {
            last_nonzero_reward_tag = 12;
            change_indicator_tag = (change_indicator_tag == 15) ? 16 : (change_indicator_tag == 16) ? 17 : 15;
        }
        // If current_reward == 0, keep last_nonzero_reward_tag unchanged and don't cycle change_indicator_tag
        
        if (env->game_over())
        {
            // Save episode data
            episodic_scores.push_back(current_episode_score);
            episode_lengths.push_back(step_counter);
            std::cout << "Episode ended - Score: " << current_episode_score << ", Length: " << step_counter << std::endl;
            
            env->reset_game();
            step_counter = 0;
            current_episode_score = 0;
            last_nonzero_reward_tag = 10;
            change_indicator_tag = 15;
        }
        if(step_counter > 27000)
        {
            std::cout << "Resetting game after 27000 steps" << std::endl;
            
            // Save episode data
            episodic_scores.push_back(current_episode_score);
            episode_lengths.push_back(step_counter);
            std::cout << "Episode ended - Score: " << current_episode_score << ", Length: " << step_counter << std::endl;
            
            env->reset_game();
            step_counter = 0;
            current_episode_score = 0;
            last_nonzero_reward_tag = 10;
            change_indicator_tag = 15;
        }
        env->getScreenRGB(input_image);

        if (ImGui::IsKeyPressed(ImGuiKey_Q, false))
        {
            done = true;
        }
        if (ImGui::IsKeyPressed(ImGuiKey_T, false))
        {
            to_render_flags_map["corner_tags"] = !to_render_flags_map["corner_tags"];
        }
        if (ImGui::IsKeyPressed(ImGuiKey_F, false))
        {
            show_fps = !show_fps;
        }

        if (show_fps)
        {
            const float tag_size = 120.f * frac;
            const float left_tag_center_x = tag_size * 0.5f;
            const float left_tag_gap_center_y = (tag_size + (screen_height - 120) * frac) * 0.5f;
            ImGui::SetNextWindowPos(
                ImVec2(left_tag_center_x, left_tag_gap_center_y),
                ImGuiCond_Always,
                ImVec2(0.5f, 0.5f));
            ImGui::SetNextWindowBgAlpha(0.5f);
            ImGui::Begin("FPS", nullptr,
                         ImGuiWindowFlags_NoDecoration | ImGuiWindowFlags_AlwaysAutoResize | ImGuiWindowFlags_NoInputs);
            ImGui::Text("FPS: %.1f", fps_estimate);
            ImGui::End();
        }

        ImGui::Render();
        SDL_RenderSetScale(renderer, 1,
                           1);
        ImVec4 clear_color = ImVec4(0.0f, 0.0f, 0.0f, 1.00f);

        SDL_SetRenderDrawColor(
            renderer, (Uint8)(clear_color.x * 255), (Uint8)(clear_color.y * 255),
            (Uint8)(clear_color.z * 255), (Uint8)(clear_color.w * 255));
        SDL_RenderClear(renderer);

        void* pixels;
        int pitch;
        SDL_Rect dst;

        if (SDL_LockTexture(game_screen, nullptr, &pixels, &pitch) < 0)
        {
            std::cerr << "Failed to lock texture: " << SDL_GetError() << std::endl;
        }
        std::memcpy(pixels, input_image.data(), pitch * env->getHeight());
        SDL_UnlockTexture(game_screen);
        dst = {int(193 * frac), int(44 * frac), int(930 * frac), int(647 * frac)};
        SDL_RenderCopy(renderer, game_screen, nullptr, &dst);


        // We make the four corner apriltags
        int size_april_tag = 120;
        if (to_render_flags_map["corner_tags"])
        {
            dst = {0, 0, int(size_april_tag * frac), int(size_april_tag * frac)};
            SDL_RenderCopy(renderer, aprilTagTextures[0], nullptr, &dst);

            dst = {
                screen_width * frac - (int(frac * size_april_tag)), 0, int(frac * size_april_tag),
                int(frac * size_april_tag)
            };
            SDL_RenderCopy(renderer, aprilTagTextures[1], nullptr, &dst);
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

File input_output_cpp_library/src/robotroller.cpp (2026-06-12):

// Copyright 2026 Keen Technologies, Inc.
//
// Licensed under the Apache License, Version 2.0 (the "License");
// you may not use this file except in compliance with the License.
// You may obtain a copy of the License at
//
//     http://www.apache.org/licenses/LICENSE-2.0
//
// Unless required by applicable law or agreed to in writing, software
// distributed under the License is distributed on an "AS IS" BASIS,
// WITHOUT WARRANTIES OR CONDITIONS OF ANY KIND, either express or implied.
// See the License for the specific language governing permissions and
// limitations under the License.

#include "../include/robotroller.h"
#include "../include/servo.h"
#include <thread>
#include <chrono>
#include <iostream>
#include <cstdlib>

#define PROTOCOL_VERSION 2.0

Robotroller::ServoPositions Robotroller::getPositionsForAction(int action)
{
    ServoPositions positions[18] = {
        {dpad_servo_default, dpad_servo_default, button_servo_default}, // 0: NOOP
        {dpad_servo_default, dpad_servo_default, button_deflection}, // 1: FIRE
        {dpad_servo_default, dpad_servo_up, button_servo_default}, // 2: UP
        {dpad_servo_right, dpad_servo_default, button_servo_default}, // 3: RIGHT
        {dpad_servo_left, dpad_servo_default, button_servo_default}, // 4: LEFT
        {dpad_servo_default, dpad_servo_down, button_servo_default}, // 5: DOWN
        {dpad_servo_right, dpad_servo_up, button_servo_default}, // 6: UPRIGHT
        {dpad_servo_left, dpad_servo_up, button_servo_default}, // 7: UPLEFT
        {dpad_servo_right, dpad_servo_down, button_servo_default}, // 8: DOWNRIGHT
        {dpad_servo_left, dpad_servo_down, button_servo_default}, // 9: DOWNLEFT
        {dpad_servo_default, dpad_servo_up, button_deflection}, // 10: UPFIRE
        {dpad_servo_right, dpad_servo_default, button_deflection}, // 11: RIGHTFIRE
        {dpad_servo_left, dpad_servo_default, button_deflection}, // 12: LEFTFIRE
        {dpad_servo_default, dpad_servo_down, button_deflection}, // 13: DOWNFIRE
        {dpad_servo_right, dpad_servo_up, button_deflection}, // 14: UPRIGHTFIRE
        {dpad_servo_left, dpad_servo_up, button_deflection}, // 15: UPLEFTFIRE
        {dpad_servo_right, dpad_servo_down, button_deflection}, // 16: DOWNRIGHTFIRE
        {dpad_servo_left, dpad_servo_down, button_deflection} // 17: DOWNLEFTFIRE
    };

    return positions[action];
}


Robotroller::Robotroller(std::string device_path, int baud_rate, int position_d_gain, int position_i_gain, int position_p_gain,
                         int dpad_servo_default, int dpad_servo_right, int dpad_servo_left, int dpad_servo_up, int dpad_servo_down,
                         int button_servo_default, int button_deflection)
    : portHandler(nullptr),
      packetHandler(nullptr),
      fire_servo(nullptr),
      left_right_servo(nullptr),
      up_down_servo(nullptr),
      dpad_servo_default(dpad_servo_default),
      dpad_servo_right(dpad_servo_right),
      dpad_servo_left(dpad_servo_left),
      dpad_servo_up(dpad_servo_up),
      dpad_servo_down(dpad_servo_down),
      button_servo_default(button_servo_default),
      button_deflection(button_deflection),
      robotroller_thread_is_running(true),
      new_action_to_execute(-1), 
      last_action_executed(0)
{
    // Create and initialize port handler
    std::cout << "[Robotroller] Attempting to open serial port: " << device_path << std::endl;
    portHandler = dynamixel::PortHandler::getPortHandler(device_path.c_str());

    if (!portHandler->openPort())
    {
        std::cerr << "[Robotroller] Failed to open the serial port to dynamixel motors!" << std::endl;
        exit(1);
    }
    std::cout << "[Robotroller] Succeeded to open the port!" << std::endl;
    
    // Set baud rate
    if (!portHandler->setBaudRate(baud_rate))
    {
        std::cerr << "[Robotroller] Failed to set baud rate to " << baud_rate << std::endl;
        portHandler->closePort();
        exit(1);
    }
    std::cout << "[Robotroller] Baud rate set to " << baud_rate << std::endl;
    
    // Clear any garbage in serial buffers
    portHandler->clearPort();
    
    // Create packet handler
    packetHandler = dynamixel::PacketHandler::getPacketHandler(PROTOCOL_VERSION);
    
    // Initialize servos with shared port and packet handlers
    fire_servo = new Servo(50, portHandler, packetHandler);
    left_right_servo = new Servo(51, portHandler, packetHandler);
    up_down_servo = new Servo(52, portHandler, packetHandler);
    
    list_of_servos.push_back(fire_servo);
    list_of_servos.push_back(left_right_servo);
    list_of_servos.push_back(up_down_servo);
    fire_servo->disableTorque();
    fire_servo->setModeToPosition();
    if (position_d_gain > 0)
    {
        fire_servo->setPositionDGain(position_d_gain);
    }
    if (position_i_gain > 0)
    {
        fire_servo->setPositionIGain(position_i_gain);
    }
    if (position_p_gain > 0)
    {
        fire_servo->setPositionPGain(position_p_gain);
    }
    fire_servo->enableTorque();

    up_down_servo->disableTorque();
    up_down_servo->setModeToPosition();
    if (position_d_gain > 0)
    {
        up_down_servo->setPositionDGain(position_d_gain);
    }
    if (position_i_gain > 0)
    {
        up_down_servo->setPositionIGain(position_i_gain);
    }
    if (position_p_gain > 0)
    {
        up_down_servo->setPositionPGain(position_p_gain);
    }
    up_down_servo->enableTorque();

    left_right_servo->disableTorque();
    left_right_servo->setModeToPosition();
    if (position_d_gain > 0)
    {
        left_right_servo->setPositionDGain(position_d_gain);
    }
    if (position_i_gain > 0)
    {
        left_right_servo->setPositionIGain(position_i_gain);
    }
    if (position_p_gain > 0)
    {
        left_right_servo->setPositionPGain(position_p_gain);
    }
    left_right_servo->enableTorque();
    
    // Start the command thread
    robotroller_thread = std::thread(&Robotroller::sendCommandsToServos, this);
}

Robotroller::~Robotroller()
{
    // Stop the thread
    robotroller_thread_is_running = false;
    
    // Wait for thread to finish
    if (robotroller_thread.joinable())
    {
        robotroller_thread.join();
    }
    
    // Delete servos
    fire_servo->disableTorque();
    left_right_servo->disableTorque();
    up_down_servo->disableTorque();
    delete fire_servo;
    delete left_right_servo;
    delete up_down_servo;
    
    // Close port when robotroller is destroyed
    if (portHandler != nullptr)
    {
        portHandler->closePort();
    }
}
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

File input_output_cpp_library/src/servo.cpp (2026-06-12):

// Copyright 2026 Keen Technologies, Inc.
//
// Licensed under the Apache License, Version 2.0 (the "License");
// you may not use this file except in compliance with the License.
// You may obtain a copy of the License at
//
//     http://www.apache.org/licenses/LICENSE-2.0
//
// Unless required by applicable law or agreed to in writing, software
// distributed under the License is distributed on an "AS IS" BASIS,
// WITHOUT WARRANTIES OR CONDITIONS OF ANY KIND, either express or implied.
// See the License for the specific language governing permissions and
// limitations under the License.

#include "../include/servo.h"

Servo::~Servo()
{
    std::cout << "Destructor called for servo " << this->id << "\n";
    this->disableTorque();
}

void Servo::setPosition(int position)
{
    uint8_t dxl_error = 0;
    auto dxl_comm_result = pck_handler_->write4ByteTxRx(portHandler, this->id, ADDR_GOAL_POSITION,
                                                        position, &dxl_error);
    if (!Servo::logDynamixelErrors(pck_handler_, dxl_comm_result, dxl_error))
    {
        std::cout << "Failed to set position of servo " << this->id << "\n";
    }
}

void Servo::setPositionDGain(int d_gain)
{
    uint8_t dxl_error = 0;
    auto dxl_comm_result = pck_handler_->write2ByteTxRx(portHandler, this->id, ADDR_POSITION_D_GAIN,
                                                        d_gain, &dxl_error);
    if (!Servo::logDynamixelErrors(pck_handler_, dxl_comm_result, dxl_error))
    {
        std::cout << "Failed to set Position D Gain of servo " << this->id << "\n";
    }
}

void Servo::setPositionIGain(int i_gain)
{
    uint8_t dxl_error = 0;
    auto dxl_comm_result = pck_handler_->write2ByteTxRx(portHandler, this->id, ADDR_POSITION_I_GAIN,
                                                        i_gain, &dxl_error);
    if (!Servo::logDynamixelErrors(pck_handler_, dxl_comm_result, dxl_error))
    {
        std::cout << "Failed to set Position I Gain of servo " << this->id << "\n";
    }
}

void Servo::setPositionPGain(int p_gain)
{
    uint8_t dxl_error = 0;
    auto dxl_comm_result = pck_handler_->write2ByteTxRx(portHandler, this->id, ADDR_POSITION_P_GAIN,
                                                        p_gain, &dxl_error);
    if (!Servo::logDynamixelErrors(pck_handler_, dxl_comm_result, dxl_error))
    {
        std::cout << "Failed to set Position P Gain of servo " << this->id << "\n";
    }
}

int16_t Servo::getPresentCurrent()
{
    uint16_t current = 0;
    uint8_t dxl_error = 0;
    auto dxl_comm_result = pck_handler_->read2ByteTxRx(portHandler, this->id, ADDR_PRESENT_CURRENT,
                                                       &current, &dxl_error);

    Servo::logDynamixelErrors(pck_handler_, dxl_comm_result, dxl_error);
    return static_cast<int16_t>(current);
}

int Servo::getPresentPosition()
{
    uint32_t position = 0;
    uint8_t dxl_error = 0;
    auto dxl_comm_result = pck_handler_->read4ByteTxRx(portHandler, this->id, ADDR_PRESENT_POSITION,
                                                       &position, &dxl_error);

    Servo::logDynamixelErrors(pck_handler_, dxl_comm_result, dxl_error);
    return static_cast<int>(position);
}


bool Servo::logDynamixelErrors(
    dynamixel::PacketHandler* packetHandler,
    const int& dxl_comm_result, const uint8_t& dxl_error)
{
    if (dxl_comm_result != COMM_SUCCESS)
    {
        printf("%s\n", packetHandler->getTxRxResult(dxl_comm_result));
        return false;
    }
    else if (dxl_error != 0)
    {
        printf("%s\n", packetHandler->getRxPacketError(dxl_error));
        return false;
    }
    return true;
}
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

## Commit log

2026-06-12 Add STL files
    [Back.stl, Front.stl, base_plate.stl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]
2026-06-12 Add a sample agent that picks random actions
2026-06-14 Add 3d models files
    [Back.stl, Front.stl, base_plate.stl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]
